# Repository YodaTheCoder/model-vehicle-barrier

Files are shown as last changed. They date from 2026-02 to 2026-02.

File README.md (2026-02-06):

# Arduino Barrier Gate with Ultrasonic Detection, Stepper Motor, and Traffic Lights

This project implements a **miniature vehicle barrier / gate system** using an Arduino Nano.  
It detects approaching vehicles with an ultrasonic sensor, raises and lowers a barrier using a stepper motor, and provides clear **red/green traffic-light feedback** via NeoPixel LEDs.

The design supports:
- Automatic operation via ultrasonic sensing
- Manual *fine alignment* of the barrier at power-on using a jog button
- A hardware switch to reverse direction so the barrier can be mounted on **either side of the road**
- Fully non-blocking motor and sensor logic

---

## Features

- 🚗 **HC-SR04 ultrasonic detection**
- ⚙️ **28BYJ-48 stepper motor with ULN2003 driver**
- 🚦 **NeoPixel traffic lights**
  - Red when barrier is down or moving
  - Green only when barrier is fully up
- ↔️ **Direction reverse slide switch**
- 🎯 **Jog button** for precise alignment when the barrier is down
- ⏱️ Non-blocking code using `AccelStepper`
- 🔌 External motor power (no brown-outs)

### Video Demo

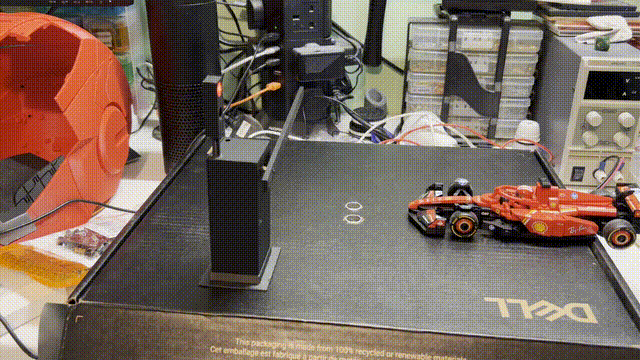
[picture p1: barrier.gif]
Watch the demo


---

## Hardware Overview

### Core Components
- Arduino Nano (ATmega328P)
- HC-SR04 Ultrasonic Distance Sensor
- 28BYJ-48 5V Stepper Motor
- ULN2003 Stepper Driver Board
- WS2812B / NeoPixel RGB LED strip (2 LEDs)
- SPDT slide switch (2-position) (2, one for barrier direction and one for power on/off)
- Momentary push button
- External 5V power supply (≥1A recommended)

---

## Wiring Diagram (Text)

```
Arduino Nano
============

POWER (COMMON GROUND REQUIRED)
------------------------------
Arduino GND  ------------------ External PSU GND
External 5V  ------------------ HC-SR04 VCC
External 5V  ------------------ ULN2003 +
External 5V  ------------------ NeoPixel 5V

ULTRASONIC SENSOR (HC-SR04)
---------------------------
TRIG  -> D9
ECHO  -> D10
VCC   -> 5V
GND   -> GND

STEPPER DRIVER (ULN2003)
-----------------------
IN1 -> D5
IN2 -> D6
IN3 -> D7
IN4 -> D8
+   -> External 5V
-   -> GND

Stepper motor plugs directly into ULN2003 board.
Leave the jumper fitted on the ULN2003 board.

NEOPIXEL TRAFFIC LIGHTS (2 LEDs)
--------------------------------
DIN  -> D4
5V   -> External 5V
GND  -> GND

LED index usage:
- LED 0 = Green
- LED 1 = Red

DIRECTION SWITCH (SPDT)
-----------------------
COM (middle pin) -> D3
One outer pin    -> GND
Other outer pin  -> Not connected

JOG BUTTON (Momentary)
---------------------
One side -> D2
Other    -> GND
```

```
                 ┌─────────────────────────────────┐
                 │           Arduino Nano          │
                 │                                 │
                 │  ┌─────────┐                    │
                 │  │ USB /   │                    │
                 │  │ Serial  │                    │
                 │  └─────────┘                    │
                 │                                 │
 D13  (unused) ──┤ D13                         RAW ├── (unused)
 D12  (unused) ──┤ D12                         GND ├── GND (common)
 D11  (unused) ──┤ D11                         RST ├── (unused)
 D10  HC-SR04 ───┤ D10  → Echo                  5V ├── 5V (logic only)
 D9   HC-SR04 ───┤ D9   ← Trig                  A7 ├── (unused)
 D8   ULN2003 ───┤ D8   ← IN4                   A6 ├── (unused)
 D7   ULN2003 ───┤ D7   ← IN3                   A5 ├── (unused)
 D6   ULN2003 ───┤ D6   ← IN2                   A4 ├── (unused)
 D5   ULN2003 ───┤ D5   ← IN1                   A3 ├── (unused)
 D4   NeoPixel ──┤ D4   ← DIN                   A2 ├── (unused)
 D3   Dir Switch ┤ D3   → Reverse switch        A1 ├── (unused)
 D2   Jog Btn ───┤ D2   → Jog button            A0 ├── (unused)
                 │                                 │
                 │ All inputs (→) use INPUT_PULLUP │
                 │ All grounds are common          │
                 └─────────────────────────────────┘
```

> ⚠️ **Important:**  
> All grounds (Arduino, stepper PSU, NeoPixels, sensors) **must be connected together**.

---

## 3D Model / Enclosure

A 3D printable enclosure model is included in this project:
- **barrier.3mf** – Complete 3D model of the electronics enclosure (3MF format)
- **barrier.f3d** – Native Fusion 360 design file (editable)
- **barrier.step** – Standard STEP format for CAD interoperability
- **barrier.csv** – Dimensions and specifications of various aspects of the 3D model

You can open these files in Fusion 360, Blender, FreeCAD, or other CAD tools to view, modify, or print the enclosure.

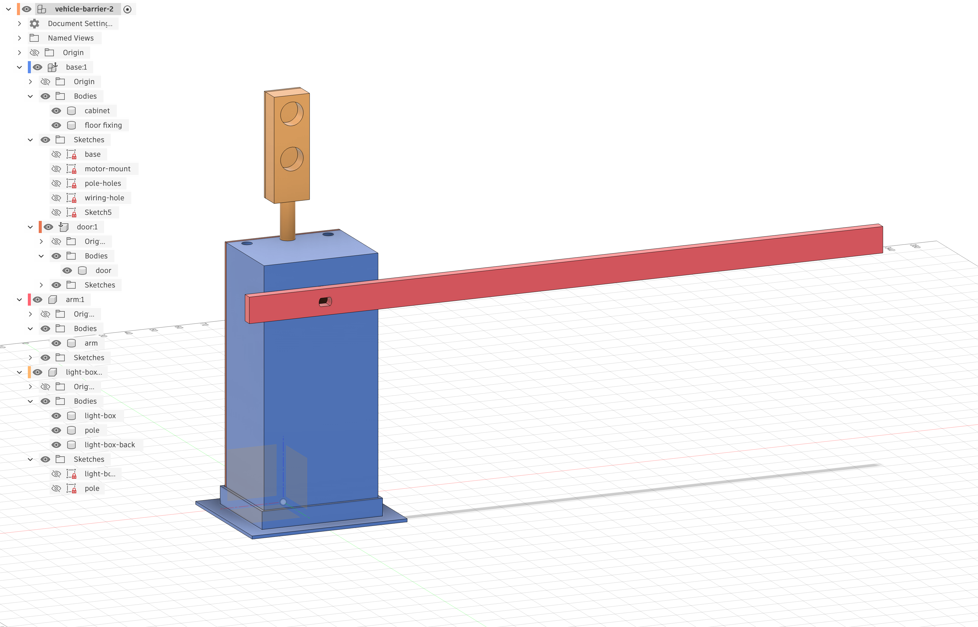
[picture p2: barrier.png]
Barrier Enclosure


---

## Behaviour Summary

### Automatic Mode
- Vehicle detected within threshold → barrier raises
- Vehicle leaves → barrier lowers after delay
- Red light is on unless the barrier is fully raised

### Jog Button (Calibration)
- Works **only when the barrier is down and stationary**
- Each button press nudges the barrier by a small number of steps
- Intended for initial alignment so the barrier is parallel to the ground
- Once aligned, the jog button is typically no longer used

### Direction Switch
- Allows the barrier to operate correctly when mounted on either side
- No code changes required

---

## Bill of Materials (BOM)

| Qty | Item |
|---:|---|
| 1 | [Arduino Nano](https://www.amazon.co.uk/dp/B0CX1B4X7M) (ATmega328P) |
| 1 | [HC-SR04 Ultrasonic Sensor](https://www.amazon.co.uk/YeBetter-Ultrasonic-Distance-Rangefinder-Detection/dp/B086VH9T9G/ref=sr_1_4) |
| 1 | [28BYJ-48 5V Stepper Motor](https://www.amazon.co.uk/Generic-28BYJ-48-Stepper-ULN2003-Driver/dp/B0DLV2DMYB/ref=sr_1_9) |
| 1 | ULN2003 Stepper Driver Board |
| 1 | [WS2812B / NeoPixel LED strip](https://www.amazon.co.uk/BTF-LIGHTING-Individual-Addressable-60Pixels-Non-Waterproof/dp/B088BRY2SH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) (2 LEDs) |
| 2 | [SPDT slide switch](https://www.amazon.co.uk/Switches-Positions-Vertical-Mounting-Electronic/dp/B0F7R18ZMT/ref=sr_1_9) (2-position, 3-pin) |
| 1 | [Momentary push button](https://www.amazon.co.uk/DAOKAI-Momentary-Miniature-Electronic-Components/dp/B09WVDCJVB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) |
| 1 | External 5V power supply (≥1A recommended) |
| 1 | 330–470Ω resistor (NeoPixel data line, optional but recommended) |
| 1 | 100–470µF electrolytic capacitor (across 5V/GND near motor driver, recommended) |
| — | Jumper wires, breadboard or PCB |

---

## Software Requirements

- Arduino IDE
- Libraries:
  - **AccelStepper** by Mike McCauley
  - **Adafruit NeoPixel**

Install via **Arduino IDE → Library Manager**.

---

## License

This project is provided as-is for learning and hobby use.  
Feel free to fork, modify, and adapt it for your own projects.

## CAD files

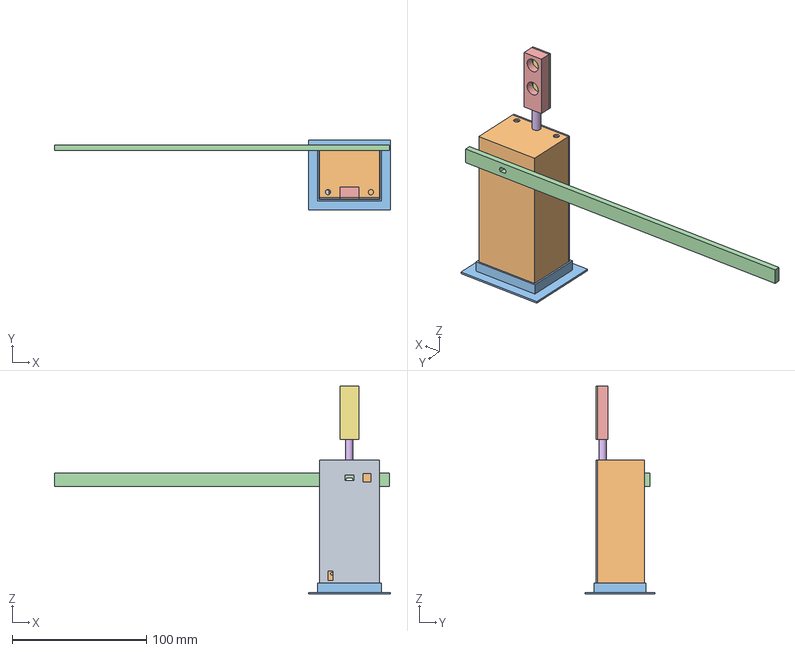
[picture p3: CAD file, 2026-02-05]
barrier.step
250.6 x 52.4 x 155.0 mm

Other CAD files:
barrier.3mf
barrier.f3d

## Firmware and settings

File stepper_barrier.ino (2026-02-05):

#include <AccelStepper.h>
#include <Adafruit_NeoPixel.h>

/* =========================
   PIN CONFIG
   ========================= */
const int TRIG_PIN = 9;
const int ECHO_PIN = 10;
const int DIR_SWITCH_PIN = 3;
const int JOG_BUTTON_PIN = 2;

// ULN2003 pins (IN1, IN3, IN2, IN4)
AccelStepper stepper(
  AccelStepper::HALF4WIRE,
  5, 7, 6, 8
);

// NeoPixel
const int NEOPIXEL_PIN = 4;
const int NUM_LEDS = 2;
Adafruit_NeoPixel pixels(NUM_LEDS, NEOPIXEL_PIN, NEO_GRB + NEO_KHZ800);

/* =========================
   BARRIER CONFIG
   ========================= */
const long BARRIER_RANGE = 1000;            // travel in steps from DOWN to UP
const int  CLOSE_DISTANCE_CM = 20;
const unsigned long LOWER_DELAY_MS = 3000;

/* =========================
   JOG CONFIG
   ========================= */
const int JOG_STEP_SIZE = 5;               // steps per press (fine adjust)
const unsigned long JOG_DEBOUNCE_MS = 50;  // simple debounce

/* =========================
   STEPPER TUNING
   ========================= */
const float MAX_SPEED    = 1500.0;  // steps/sec
const float ACCELERATION = 2000.0;  // steps/sec^2

/* =========================
   ULTRASONIC TIMING
   ========================= */
const unsigned long US_INTERVAL_MS = 50;
const unsigned long US_TIMEOUT_US  = 25000;

/* =========================
   ULTRASONIC STATE
   ========================= */
enum UltrasonicState { US_IDLE, US_WAIT_RISE, US_WAIT_FALL };
UltrasonicState usState = US_IDLE;

unsigned long usLastPingMs   = 0;
unsigned long usTriggerAtUs  = 0;
unsigned long usEchoRiseAtUs = 0;
float lastDistanceCm = -1;

/* =========================
   BARRIER STATE
   ========================= */
bool vehiclePresent = false;
unsigned long vehicleClearedAt = 0;

/* =========================
   CALIBRATED DOWN POSITION
   ========================= */
long downPos = 0;  // this is what the jog button calibrates

void setup() {
  pinMode(TRIG_PIN, OUTPUT);
  pinMode(ECHO_PIN, INPUT);
  pinMode(DIR_SWITCH_PIN, INPUT_PULLUP);
  pinMode(JOG_BUTTON_PIN, INPUT_PULLUP);

  digitalWrite(TRIG_PIN, LOW);

  stepper.setMaxSpeed(MAX_SPEED);
  stepper.setAcceleration(ACCELERATION);
  stepper.setCurrentPosition(0);

  pixels.begin();
  pixels.clear();
  pixels.show();

  Serial.begin(9600);
  Serial.println("Barrier system ready (jog calibrates DOWN)");
}

void loop() {
  unsigned long nowMs = millis();

  // Always run stepper
  stepper.run();

  // Direction (side of road)
  bool reverse = (digitalRead(DIR_SWITCH_PIN) == LOW);

  long upPos = downPos + (reverse ? -BARRIER_RANGE : BARRIER_RANGE);

  /* =========================
     JOG BUTTON (MULTI-PRESS, DOWN ONLY)
     ========================= */
  static bool lastJogState = HIGH;
  static unsigned long lastJogEdgeAt = 0;

  bool jogState = digitalRead(JOG_BUTTON_PIN);

  // "Down / red light on" in your system means: not fully up.
  // But we also only want jog when we're stationary at the DOWN target (not mid-move).
  bool atDownTarget =
    (stepper.distanceToGo() == 0) &&
    (stepper.currentPosition() == downPos) &&
    (stepper.targetPosition() == downPos);

  if (atDownTarget &&
      lastJogState == HIGH && jogState == LOW &&
      (nowMs - lastJogEdgeAt) >= JOG_DEBOUNCE_MS) {

    lastJogEdgeAt = nowMs;

    long jogDelta = reverse ? -JOG_STEP_SIZE : JOG_STEP_SIZE;

    // Calibrate DOWN by nudging the down target itself
    downPos += jogDelta;

    // Command motor to the new DOWN target
    stepper.moveTo(downPos);

    Serial.print("Jog: new downPos = ");
    Serial.println(downPos);
  }

  lastJogState = jogState;

  /* =========================
     UPDATE ULTRASONIC (NON-BLOCKING)
     ========================= */
  updateUltrasonic();

  /* =========================
     AUTOMATIC BARRIER LOGIC
     ========================= */
  if (lastDistanceCm >= 0) {

    if (lastDistanceCm <= CLOSE_DISTANCE_CM) {
      vehiclePresent = true;
      vehicleClearedAt = 0;

      if (stepper.targetPosition() != upPos) {
        stepper.moveTo(upPos);
      }
    } else {
      if (vehiclePresent) {
        vehiclePresent = false;
        vehicleClearedAt = nowMs;
      }

      if (vehicleClearedAt > 0 &&
          nowMs - vehicleClearedAt >= LOWER_DELAY_MS &&
          stepper.targetPosition() != downPos) {

        stepper.moveTo(downPos);
      }
    }
  }

  updateTrafficLights(upPos);
}

/* =========================
   FIXED NON-BLOCKING ULTRASONIC
   ========================= */
void updateUltrasonic() {
  unsigned long nowMs = millis();
  unsigned long nowUs = micros();

  switch (usState) {
    case US_IDLE:
      if (nowMs - usLastPingMs >= US_INTERVAL_MS) {
        digitalWrite(TRIG_PIN, LOW);
        delayMicroseconds(2);
        digitalWrite(TRIG_PIN, HIGH);
        delayMicroseconds(10);
        digitalWrite(TRIG_PIN, LOW);

        usLastPingMs  = nowMs;
        usTriggerAtUs = nowUs;
        usState = US_WAIT_RISE;
      }
      break;

    case US_WAIT_RISE:
      if (digitalRead(ECHO_PIN) == HIGH) {
        usEchoRiseAtUs = nowUs;
        usState = US_WAIT_FALL;
      } else if (nowUs - usTriggerAtUs > US_TIMEOUT_US) {
        usState = US_IDLE;
      }
      break;

    case US_WAIT_FALL:
      if (digitalRead(ECHO_PIN) == LOW) {
        unsigned long echoDurationUs = nowUs - usEchoRiseAtUs;
        lastDistanceCm = echoDurationUs * 0.0343f / 2.0f;
        usState = US_IDLE;
      } else if (nowUs - usEchoRiseAtUs > US_TIMEOUT_US) {
        usState = US_IDLE;
      }
      break;
  }
}

/* =========================
   TRAFFIC LIGHT LOGIC
   ========================= */
void updateTrafficLights(long barrierUpPos) {
  static int lastState = -1;

  bool barrierFullyUp =
    (stepper.currentPosition() == barrierUpPos) &&
    (stepper.distanceToGo() == 0);

  int state = barrierFullyUp ? 1 : 0;

  if (state != lastState) {
    pixels.clear();

    if (barrierFullyUp) {
      pixels.setPixelColor(0, pixels.Color(0, 255, 0)); // Green (LED 0)
    } else {
      pixels.setPixelColor(1, pixels.Color(255, 0, 0)); // Red (LED 1)
    }

    pixels.show();
    lastState = state;
  }
}

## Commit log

2026-02-05 initial commit of the project
    [barrier.3mf, barrier.csv, barrier.f3d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]
2026-02-06 add Arduino pin assignment diagram
2026-02-06 add amazon links to BOM
